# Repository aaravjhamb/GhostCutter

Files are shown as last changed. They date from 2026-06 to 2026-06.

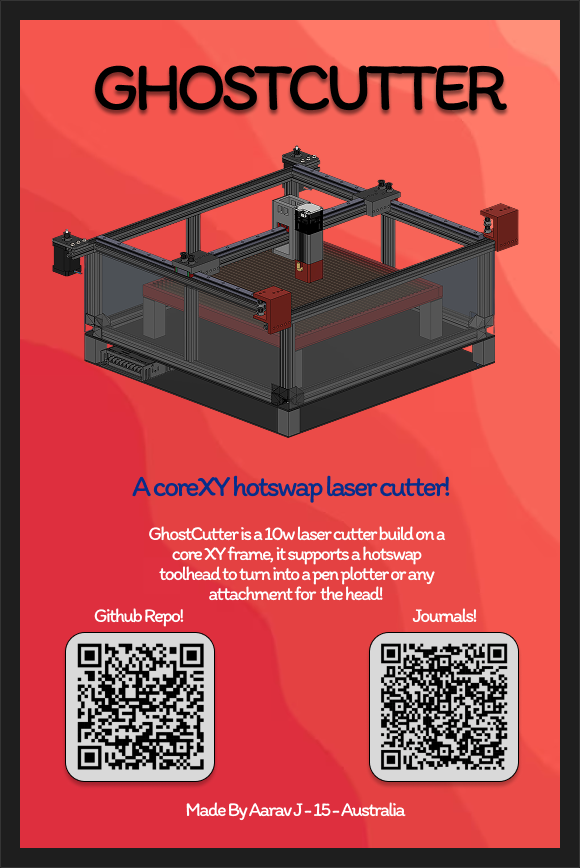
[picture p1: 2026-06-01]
zine.png

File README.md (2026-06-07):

# GhostCutter

A CoreXY diode laser cutter built on a 2020 aluminium extrusion frame.



## Overview

GhostCutter is a simple DIY coreXY designed laser cutter designed on a coreXY 3d printer like frame built for hotswap toolheads!

## Inspiration/Motivation

The main inspo for this project was that most current laser cutter's on the market on aliexpress are cheap and crappy - none of them have an easy to use software/wifi/easy to use cam (lightburn looking at you)

I set out to design a machine that solves ALL of these problems WHILE being cheaper than all the 300 dollar machines!! I also wanted a laser cutter because well,, couldn't afford one for 1k

## Setup Guide

This part is coming soon! Once I get the machine fully built I'll add instructions here + I've been working on a custom CAM software for this machine! (don't want to suffer using lightburn)

Sneak Peak (FluidBurn) - This software includes all the fancy features of lightburn while being easy to use and as intuitive as possible 

[Repo Link](http://github.com/aaravjhamb/fluidburn/)



image (6)

## Specs

| Parameter | Value |
|---|---|
| Frame | 2020 aluminium extrusion |
| Motion system | CoreXY |
| Machine footprint | 500x650mm |
| Cutting area | ~400x400mm |
| Laser module | LaserTree LT-80W-AA (10W optical) |
| Wavelength | 450nm |

## BOM

| Part | Qty | Source | Cost (USD) |
|---|-----|---|---|
| MGN12 linear rails | 3 | on hand | $30 |
| 2020 aluminium extrusion 100mm | 6 | [Core Electronics](https://core-electronics.com.au/2020-aluminium-extrusion-600mm.html) | $70 |
| 17HS24-2104S NEMA 17 stepper motors | 2 | [OMC StepperOnline](https://www.omc-stepperonline.com/nema-17-bipolar-1-8deg-65ncm-92oz-in-2-1a-3-36v-42x42x60mm-4-wires-17hs24-2104s) | $43 |
| LaserTree LT-80W-AA laser module | 1 | [LaserTree](https://lasertree.com/products/10w-optical-output-power-laser-cutter-module) | $131 |
| Air assist pump | 1 | [Sculpfun](https://www.sculpfun.com/products/sculpfun-air-pump) | $69 |
| Misc (pulleys x10, belts, screws) | 3 | aliexpress | $30 |
| 3D printed parts | NA | print farm (on hand) | $0 |
| **Total** | | | **~$347** |

> Controller board, enclosure panels, acrylic bed slats, and safety goggles not yet costed above.

# Bed Design

The bed uses a Clear acrylic slat design. This means that it uses a diode laser's inability to cut through clear acrylic as an advantage rather than a drawback. Slats slide into a 3D printed base with shallow grooves on one side and deep grooves on the other to form a slatted bed.

### Laser Head
LT-80w-AA with a 10w Optical Output - This fits on to a hotswap head

### Electronics
TBD

### Enclosure
Laser rated acrylic

## Safety

This machine uses a Class 4 laser. Permanent eye damage can occur in milliseconds.

- Always wear wavelength-appropriate laser safety goggles (OD4+ at 450nm)
- Operate only with enclosure panels in place
- Never leave unattended during operation
- Ensure that there is ventilation

## Firmware & Software

| Component | Software |
|---|---|
| Firmware | TBD |
| Slicer/CAM | Going to be custom |

## Progress Log

- [x] CAD — frame
- [x] CAD — CoreXY motion system
- [x] CAD — bed
- [x] CAD — laser head mount
- [x] CAD — enclosure
- [X] IRL — frame assembly
- [ ] IRL — motion system
- [ ] IRL — wiring & firmware
- [ ] First cut

## License

MIT

### Made by Aarav J :D

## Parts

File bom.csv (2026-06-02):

Qty | Part | Description | Source | Cost Per Item | Total Cost
6 | 2020 Aluminium Extrusions | 1000mm Extrusions for the frame (2020) | Facebook Marketplace | $12 | $72
3 | Linear Rails | Linear rails for movement - 500m MG15C | https://www.aliexpress.com/item/1005008099466600.html | $23 | $70
2 | 42BYGH40 Nema 17 | NEMA 17 Stepper motors for movement | https://littlebirdelectronics.com.au/products/nema17-stepper-motor-42bygh40-42-40mm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 | $20 | $42
1 | LT-80W-AA-PRO | Laser Head! 10W optical output | https://lasertree.com/products/10w-optical-output-power-laser-cutter-module?variant=44760191565975 | $130 usd | $160 usd
1 | Air Assist Pump | Air Assist pump for cutting | https://www.sculpfun.com/products/sculpfun-air-pump | $70 usd | $70 usd
2 | 2GT 20 teeth Timing pulley | Timing Pulley | https://www.aliexpress.com/item/1005007990994074.html?mp=1 | $1.4 | $2.8
1 | GT2 Belt PU with Steel Core GT2 Belt 2GT Timing Belt Width 6mm 10mm 9/15mm for 3D printer parts Anti-wear Reinforce Open Belt | Belt | https://www.aliexpress.com/item/4001241347091.html?mp=1 | $8.70 | $8.70
10 | GT2 16T 20T 30T 36Teeth 2GT Synchronous Timing Idler Pulley Bore 3/4/5/6/7/8mm Width 6/9/10/15mm 3D Printer Accessories 20Teeth | Idler Pulley | https://www.aliexpress.com/item/1005011766262580.html?mp=1 | $2.93 | $29.30
 |  |  | Total | $299 usd

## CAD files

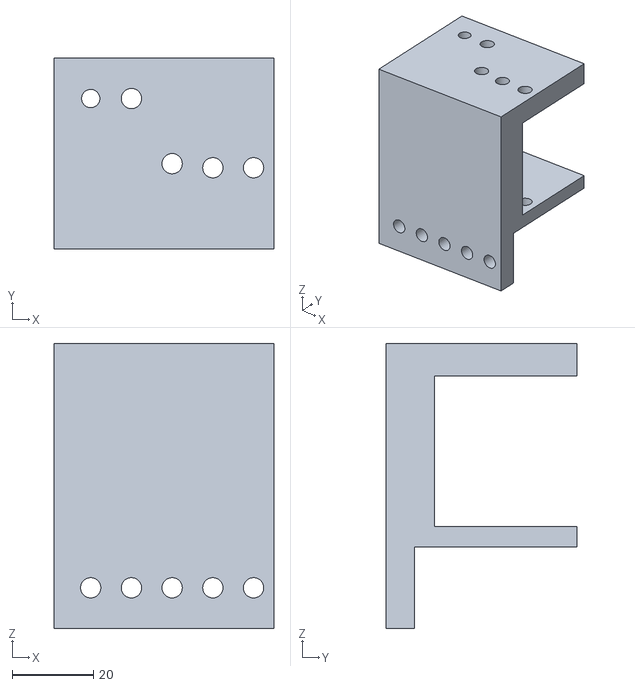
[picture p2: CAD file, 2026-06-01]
v38/3D printed Parts/Pulley Hold XY.stl
54.0 x 47.0 x 70.0

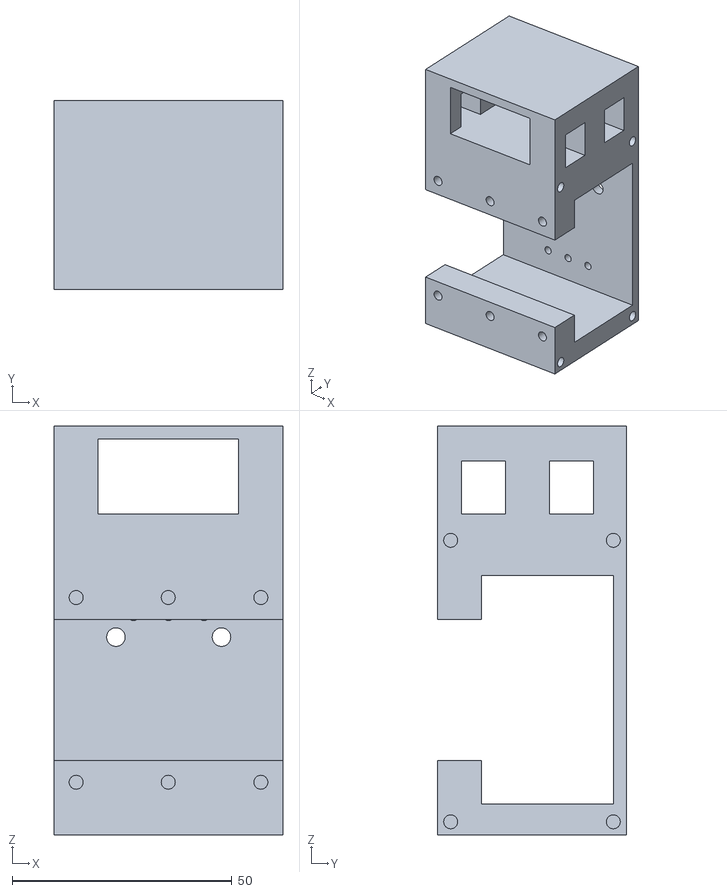
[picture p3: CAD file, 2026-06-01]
v38/3D printed Parts/Laser Tree 40W AA Linear Rail Mount.stl
52.0 x 43.0 x 93.0

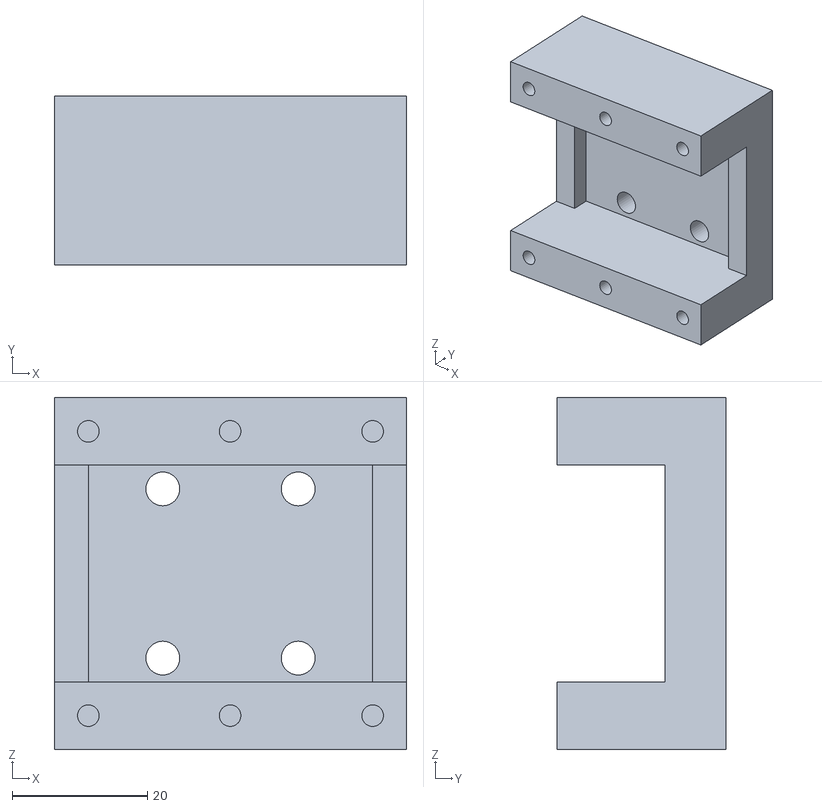
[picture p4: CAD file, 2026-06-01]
v38/3D printed Parts/Rail Mount.stl
52.0 x 25.0 x 52.0

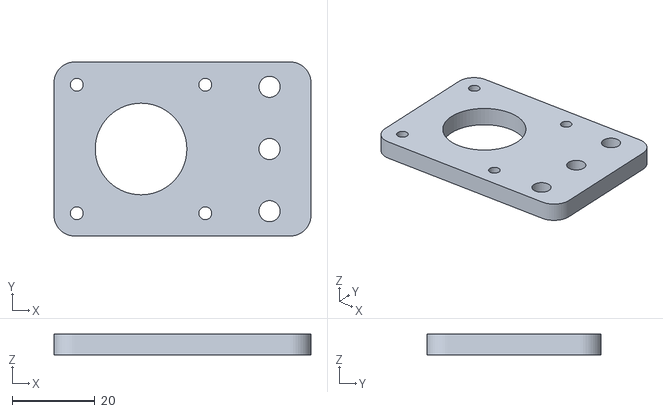
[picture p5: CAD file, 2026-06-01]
v38/3D printed Parts/NEMA 17 Mounting Plate.stl
62.0 x 42.0 x 5.00

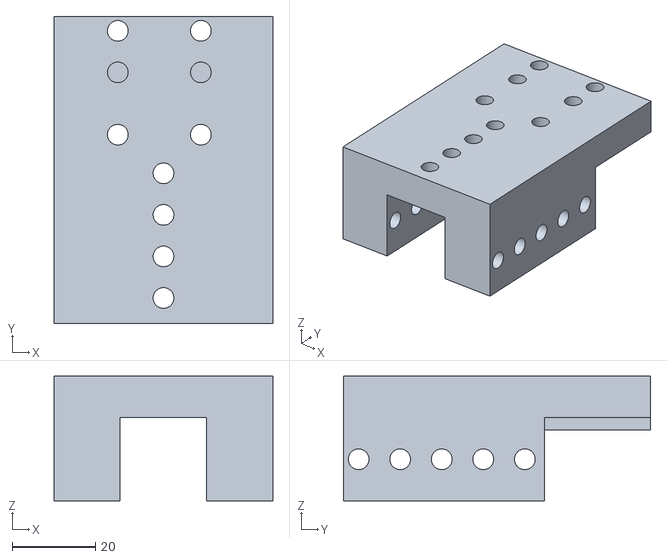
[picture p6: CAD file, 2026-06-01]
v38/3D printed Parts/Pulley Middle Mount.stl
52.7 x 74.0 x 30.0

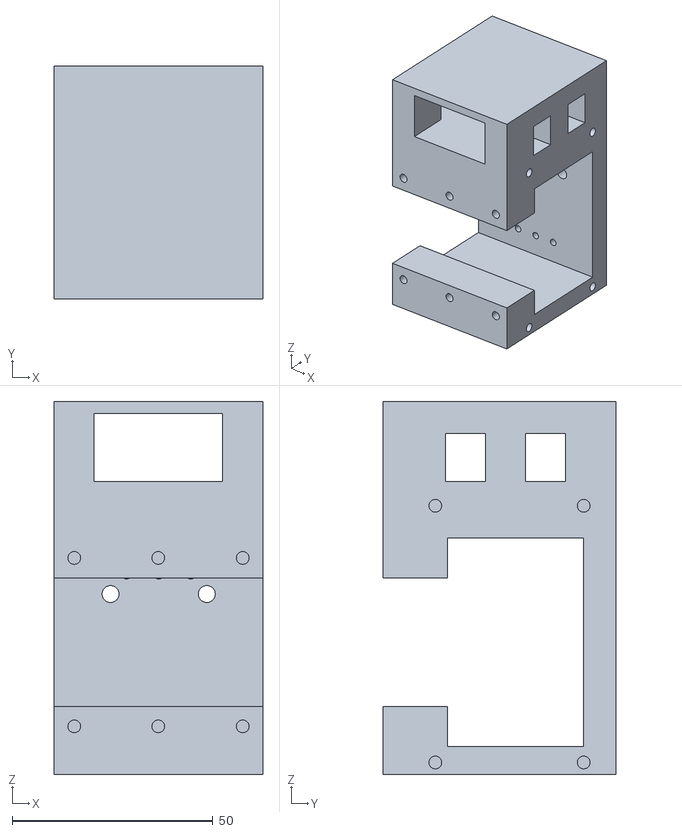
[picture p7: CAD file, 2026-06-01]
v38/3D printed Parts/Cutter Mount.stl
52.0 x 58.0 x 93.0

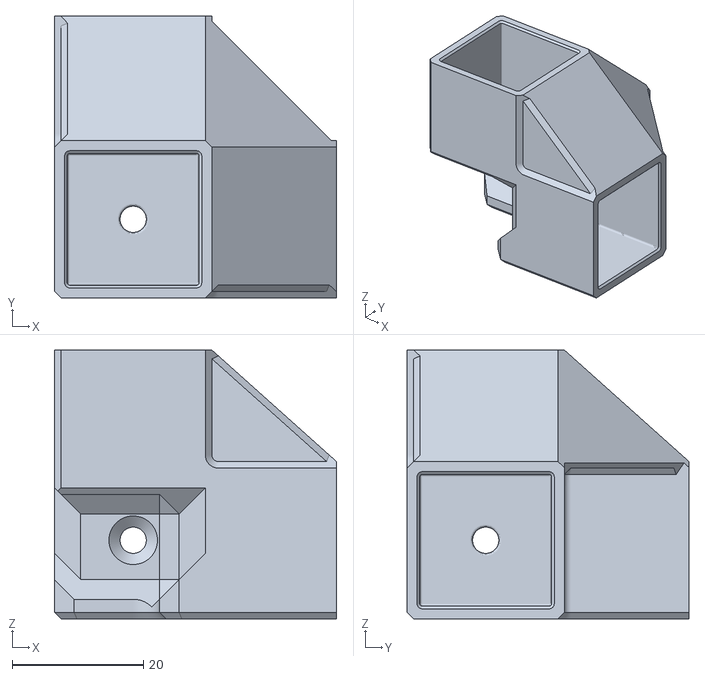
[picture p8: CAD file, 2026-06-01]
v38/3D printed Parts/2020-3-way-heavyduty-rv2 (1) (1).stl
43.0 x 43.0 x 41.0

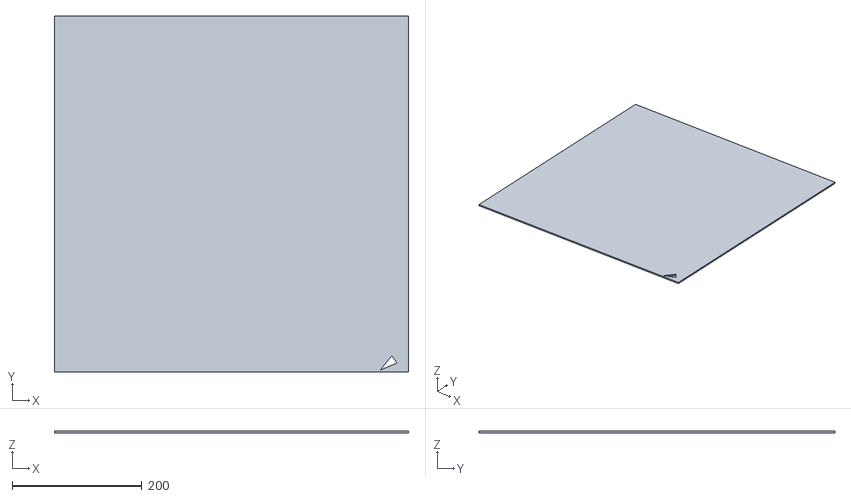
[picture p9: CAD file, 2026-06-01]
v38/3D printed Parts/Base (laser cut).stl
546.0 x 548.5 x 3.00

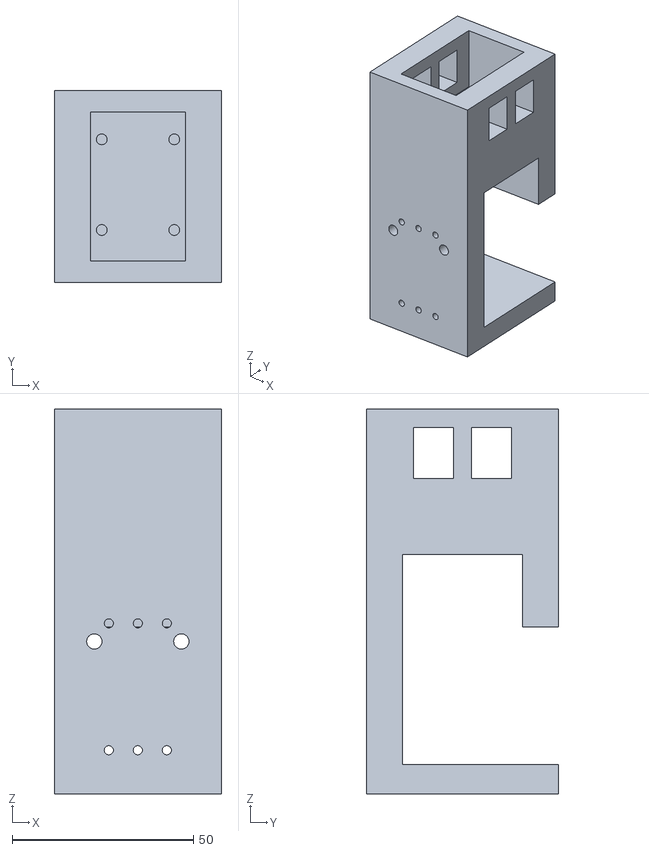
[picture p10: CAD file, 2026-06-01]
v38/3D printed Parts/Laser Mount Head.stl
46.1 x 53.0 x 106.2

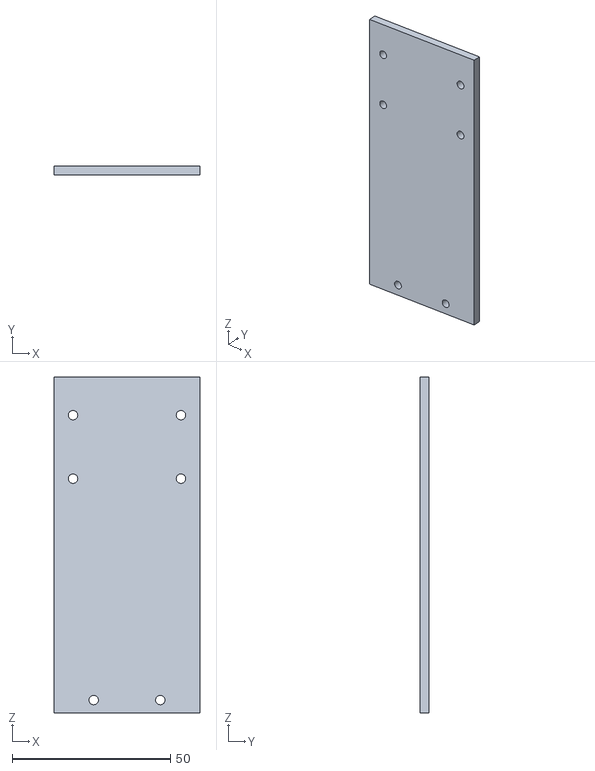
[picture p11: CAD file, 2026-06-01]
v38/3D printed Parts/Laser Mount Head Plate.stl
46.1 x 3.00 x 106.2

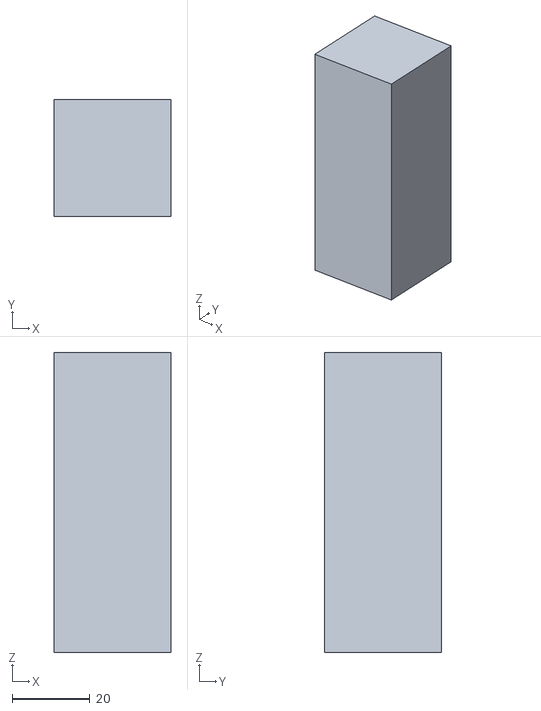
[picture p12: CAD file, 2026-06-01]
v38/3D printed Parts/Bed Support.stl
30.0 x 30.0 x 77.0

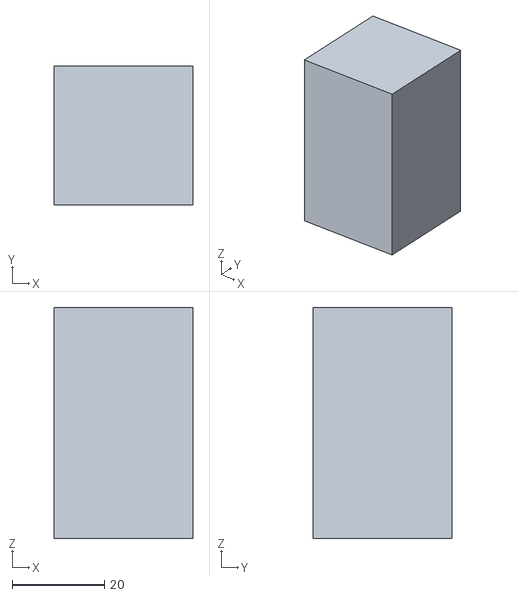
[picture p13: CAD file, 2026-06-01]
v38/3D printed Parts/Base Support.stl
30.0 x 30.0 x 50.0

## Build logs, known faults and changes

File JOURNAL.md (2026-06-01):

# GhostCutter

*Exported 2026-06-01 · 3 entries*

---

## Day 1 - Thursday, 28 May 2026 - Importing Progress
Today I started journaling by getting some of my progress from the CAD I already did, I already started a bit of this project before journaling so apologies.
The first important step was choosing what extrusions/how I was going to make the frame. I've seen and assembled/torn down a lot of 3d printers before + have an ender 5 pro on hand to take a look at. My main choice was to go with 2020 aluminium extrusions as these are light weight, popular and strong as well. I could have gone with 4040's but honestly they are too big and bulky for a simple laser cutter

Once I chose my frame I began a fusion design!
This was a rough design - sorry I don't have more pictures because this is from the past!



I decided to use corner brackets (however this is the fifth time I've changed them as I could never figure out how I'm going to make my frame).
The dimensions I chose was 500x500mm for the cuttting area however after moving on with the design I soon realised that realistically if the machine was 500x500 I would only get about 300x300 cutting area, for future versions I would like to expand on this!

The next step was to research movement systems, I chose CoreXY since I like how it works and wanted to experiment with a corexy laser cutter. Personally I haven't seen anyone build a laser cutter with a 3d printers frame and feel this would be really cool!

Since I've never made a coreXY machine before I had to do tonss of research, this included stuff like understanding corexy kinematics and how they worked



[This video](https://www.youtube.com/watch?v=_ramiM3KHYE)
Was a great resource to help me get started

Another vid I used as reference was [this one](https://www.youtube.com/watch?v=KqbJemLnnNM&pp=ygUWY29yZSB4eSBsYXNlciBlbmdyYXZlctIHCQkNCwGHKiGM7w%3D%3D)

Through this research + bugging souptik about his 3dp design I started to design the actual laser cutter.

[This](https://github.com/souptik-samanta/ChaosCompiler) design was an absolute life saver working as a great reference for me.

### Started Designing Motion Systems

I then started to design motion systems - this included having a middle rail and 2 linear rails on the side to house the y carriage 



After this I created a middle rail for the XY gantry



You can also see in this design I'm not using the corner brackets ^ One of my many changes and inability to choose what bracket I wanted to go with.

Thats it for the journal impor (I'll won't drag the journal too long)

**Time Spent : 7 hours including research, design and iterations**

---

# Day 2

Okkii whats next? I took at look at some more docs and printed some prototypes. The main focus is this prototype



The first version of this - 




^^ back when I had NO idea what I was doing with the movement gantry (had some help from a friend)

This part is what holds the entire Y gantry in place so this component is crucial as without it the cutter would collapse. If you look closer at the moddle its currently split into 2 parts however this creates unneccasary weakness in the system, to combat this the simple fix was to add material on the side and combine both parts together like so



This adds more reinforcement to the sides allowing for a singular 3d print improving strenght as well.

After adding that I also added the linear rail onto the Y gantry, I've chosen to mount it sideways for now but after looking at other designs due to bend/flex I'm going to change it to the top
  


Another change I made was to extend the front and back top rail to 650mm to allow for the motor and pulley mounts, I grabbed the motor mount from grabcad 

And planned to weld this on (future me - I'm going to switch to another plate because I don't have a welder lol)

Changing the lengths of the rod meant that I can't use my custom corner brackets anymore and I would have to use these L brackets to secure everything together. I made a crucial mistake on the bottom for these brackets and I'll explain in a bit



The next thing I added was these pulley mounts for the core XY belts as per core xy kinematics :D


 
These will route the belts around the entire gantry and are a crucial part of corexy (mount stolen from a friend @souptiksamanta) ty

I also added a 3d model of the nema 17 steppers that I'm going to be using



NOW time for the big mistake - 


Didja spot it? I made a huge mistake down here


By switching to these brackets, the problem with them is since they are plastic there is a tiny bit of flex so making a square with 4 of them doesn't result in a perfect square, I only realised this AFTER i started cutting the aluminium extrusions but not to worry! it can be easily fixed by switching to my ORIGINAL design of using cubed corner brackets (I'm yet to fix this in my design)

### Part 2 - Building the bed

Have you ever thought how a laser cutter bed works? I mean the laser is *cutting* through the material so it will cut through the bed as well right? Thats where a honeycomb bed comes in, it looks something like this


 
And its basically a block of aluminium milled in a thin honeycomb pattern that basically spreads heat and doesn't allow the laser to cut it. Now the problem with using this in my case is 2 things

1 - Am I made of money - NO, is hackclub made of money - NO
2 - is this expensive and heavy - yes, do i want to use it - NO

To combat these problems I spent a couple hours with my teacher sketching possibly bed designs (I don't have the sketches unfortunatley)

TLDR I'm planning on using a diode laser for my build, what if I use its weakness to my advantage - A major weakness for a diode laser is that it cannot cut through clear/light acrylic as the 450nm blue lenght laser light cannot penentrate. This can be used to our advantage as we can make a bed out of clear acrylic to ensure the laser won't cut through it!

The problem still remains though that the acrylic will heat up due to the  laser intensity and burn anyway, to combat this I whent back to the honey comb design and came up with a design of my own. What if I made a bed that has vertical *slats* instead of a honeycomb design, slats would help spread the heat + they would also be spaced thin enough to keep the cut pieces from falling in the bed. Since I also had access to a MASSIVE co2 laser cutter at school that could cut clear acrylic + a prusa xl for the bed size I decided to take advantage of both of them.

### Part 3 - designing the bed in fusion

Ok so to start designing the bed I first layed out a bed cutting area of 400x400, my laser cutter was initially meant to be 500x500 but i kinda forgot about the mounts and whatnot that would reduce the area to 400x400, anway I started by making a base for the bed like so



I then continued by designing the slat border and slat holes for the acrylic to slide into making the final bed



Two sides are smooth and 2 sides have the slats, the smooth is just for a border and to provide a vertical boundry and the slats is where the acrylic strips will go. 

One part of the bed has lower grooves just as a resting point for the slats like so



The other side has deeper grooves for the slats to properly slide into



These 2 combined let 3mm thick acrylic strips go into the bed like so



### Final Bed



### Laser Cutter With Bed



# Time spent - ~15 hours

---

# Day 3

Day 3 lets go, couple goals for today. So far I've finished the xy gantry and the base. My next goals are to add the laser head mount (basically the X carriage that houses the laser and belt grips.

Before we get to redesigning that I need to cleanup the fusion tree. Our project currently looks like this



A tad bit messy I know, to combat this I used a lil bit of help from claude! believe it or not, claude works suprising well using the fusion mcp (it can't design things but its create for cleanup and organsing your working tree), I sent a single prompt to claude and my tree whent from looking like this



To this



AI really can be amazing sometimes :D
Alright moving on, the next thing I added was a laser mount, to do this I need to research different type's of laser available for me to use. My design uses a diode laser and I want to keep things light on the tool head and not use a bulky laser. Some of the best laser's I found where by LaserTree and they had amazing documentation online aswell!

The biggest contender's are
- LT-20W-A
- LT-40W-AA
- LT-80W AA

For this project, I'm going to choose the 80w model, this is because the 80 stands for input power and *not output power*, Instead theres a metric caled optical output that properly shows the output power, in my case for the 40w model its optical output is a 5w laser and for the 80w module its optical power is 10w which is ideal. 

To actually make the mount for it, I need to import the step file for the laser into fusion, I found the 40w AA and that should be fine for making the designs as both versions fit together



I then used the plate on the laser, extruded a plate and designed this mount around it



*Future me here, this mount was designed for a vertical mount of the laser head (meaning the rail is on the side) however I will change this to be the top and completley redesign this peice*

I then added both the laser and the mount to my cad model! 


Ok now time for the big change, I've read + seen other people's projects online and most of them mount the X rail (laser cutter head rail) on the top and not the side to prevent flex, I would rather be cautious and add this now rather than add it when something goes wrong.



I removed the laser head and carriage and added the rail on top!
After I added this rail I need to redesign the laser head mount as the old mount is designed for a side rail, Again I did the same thing taking the laser cutter's plate profile, plonking it in a new file and designing a lil bracket around it like so!



Now to patch things off I wanted to add a back panel but I didn't want to use heated inserts as my projects have gone prettty bad with them in the past with plastic clogging up my soldering iron. To combat this I brainstormed different solutions till I came up with an idea I previously used 5 years ago! 

My idea was to embed a normal m3 nut within the plastic as a press fit and then add a hole for the screw to go into, the nut would act as "metal" threads for the screw ensuring that I could screw and rescrew as many times as I wished without the threads wearning out!!

To implement this, I needed to find the m3 nut profile and design a reccess hole in fusion first!
Found an amazing resource at [this website](https://www.joom.com/en/products/6a0436ffde85040178f3c099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)



That basically showed me how to perfectly design a press fit for a m3 nut in fusion! I then designed something like this


That should technically allow me to press fit the nut inside and get a nice screw going through!

### Did it x6



### Final design with 3d models + back plate (laser cut ironically lol)



### Final design with laser cutter



# Almost done!!!
Exciting, I'm almost done! The last part is to add some safety! Especially since I'm working with lasers (class 4 laser scaryyy)
I need to add an enclosure with laser proof acrylic panels + use some special looking goggles that look like this



These are both ugly AND Expensive but I cannot stress HOW important it is to have laser goggles with a class 4, class 4 means permanent eye damage in milseconds and is EXTREMELY dangerous even WITH an enclosure - [link](https://www.amazon.com.au/xTool-Laser-Safety-Glasses-Goggles/dp/B0GMQJHD33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)

I then added a quick enclosure (clear because I wanna see the design) will be not clear irl



I then also added a little pocket at the bottom to allow for electronics and wiring to sit! 



Among the little things, also added little risers for the bed to sit in



AAAND YEAH! Thats it - the laser **"*should*"** technically be done but I'm sure more changes will be needed as I progress in the IRL build!

Picture - 


# Bonus pics 
(I've funded a lot of components myself and already started builing IRL cause I couldn't wait :P)









## I HATE TAPPING - no joke spent 4 hours tapping 16 connections





# Time spent : ~20 hours
^ probably undercounting here because I haven't included the IRL build time of cutting the rods + assembling everything
